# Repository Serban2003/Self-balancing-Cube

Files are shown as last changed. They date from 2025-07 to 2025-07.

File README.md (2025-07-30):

# Self-Balancing Cube (Cubli) with Reaction Wheels and Gyroscope

## Project Overview

This project implements a self-balancing cube (Cubli) using three reaction wheels and a gyroscope-based feedback system. The cube is capable of maintaining balance on its edges or corners using PI control loops executed on an ESP32 microcontroller.

## Objectives

- Design and fabricate a medium-scale Cubli with 3D-printed and off-the-shelf components.
- Implement and tune PI controllers for real-time balance using motor and IMU data.
- Validate closed-loop performance and test real-time response to external disturbances.
- Lay the foundation for further development, such as corner recovery or adaptive control.

## Hardware Components

| Component | Model/Specs |
|---|---|
| Microcontroller | ESP32 DevKitC |
| IMU Sensor | DF-SEN0142 (MPU6050, 6DOF) |
| Motors | Nidec 24H-series BLDC |
| Power Supply | Tattu R-Line 4S 1800mAh LiPo (14.8V) |
| Step-Down Converter | DFRobot DFR1015 (14.8V to 3.3V) |
| Mechanical Structure | Custom-designed PLA parts (Fusion 360) |
| Fasteners | M3/M4 screws, brass inserts, aluminum hubs |

## Software Stack

- **Platform:** PlatformIO (C/C++)
- **Sensor Processing:** MPU6050 (gyroscope + accelerometer)
- **Control Algorithm:** Discrete-time PI controller
- **Testing Interface:** Bluetooth (SerialBT) & MATLAB (for TF estimation)

## Control Design

1. **Motor Identification**  
   - Data collected using encoder feedback and sent over serial to MATLAB.
   - Transfer functions identified using ARX modeling.

2. **Controller Tuning**  
   - PI controllers tuned in MATLAB using `pidtune` for ωₙ ≈ 13.3 rad/s.
   - Discrete controller applied in Arduino firmware using backward difference method.

3. **Testing & Validation**  
   - Real-time control validated via encoder feedback and serial plots.
   - PID implementation maintains speed tracking and ensures system stability.

## IMU Integration & Normalization

- Gyroscope and accelerometer data is normalized using configuration-dependent scale factors defined in `current_config.h`.
- Output is logged in human-readable and CSV format using utility functions (`utils.h` and `normalizer.h`).

## File Structure

| File | Purpose |
|---|---|
| `main.cpp` | Entry point: initializes MPU6050, prints raw/normalized data |
| `motor.cpp/h` | PID control loop, encoder update, PWM output |
| `IMUQuaternion.cpp/h` | Quaternion math and orientation conversion |
| `normalizer.cpp/h` | Sensor value normalization with scale factors |
| `utils.cpp/h` | Serial print utilities (CSV, readable, binary) |
| `current_config.h` | Config for DLPF, SRD, gyro/acc range, scale constants |
| `data_types.h` | `RawValues`, `NormalizedValues`, `Angle`, `IMUQuaternion` |

## Next Steps

- [x] Validate PI controllers with encoders.
- [ ] Integrate real-time orientation feedback from IMU for full stabilization.
- [ ] Transition to aluminum frame for rigidity and weight savings.
- [ ] Implement corner-jump self-balancing and control from arbitrary position.
- [ ] Explore advanced control: Adaptive, LQR, or MPC.

---

## References

- [ETH Zürich Cubli](https://www.youtube.com/watch?v=n_6p-1J551Y)
- [MathWorks PIDTUNE](https://www.mathworks.com/help/control/ref/pidtune.html)
- [TI BLDC Fundamentals](https://www.ti.com/lit/an/slyp173/slyp173.pdf)
- [MPU6050 Datasheet](https://wiki.dfrobot.com/DF-SEN0142)
- [ESP32 Docs](https://www.espressif.com/en/products/socs/esp32/resources)
- [Nidec 24H BLDC Motors](https://www.nidec.com/)

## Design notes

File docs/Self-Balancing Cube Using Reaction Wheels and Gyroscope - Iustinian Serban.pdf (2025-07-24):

Project for Control Engineering II
Student | Șerban Iustinian-Bogdan | Group | 30135 | Grade

# Self-Balancing Cube Using Reaction Wheels and Gyroscope

University Year: 2024-2025

Author: Șerban Iustinian-Bogdan Group: 30135/2

Project for Control Engineering II
Student | Șerban Iustinian-Bogdan | Group | 30135 | Grade

## Contents

## Figures

Figure 1 - Reaction Wheel | 6
Figure 2 - ESP32-DevKitC | 7
Figure 3 - DF-SEN0142 IMU | 8
Figure 4 - Expansion Board for ESP32 | 8
Figure 5 - Nidec 24H Motor | 9
Figure 6 - DF-DFR1015 Buck Converter | 9
Figure 7 - Tattu R-Line Version 3.0 1800mAh 14.8V LiPo Battery | 9
Figure 8 – Plate | 10
Figure 9 - Plate with Slots for Mounting Brackets | 10
Figure 10 - Corner Piece | 11
Figure 11 - Electronics Support | 11
Figure 12 - Motor Mounting Bracket | 11
Figure 13 - Reaction Wheel | 12
Figure 14 - Motor Assembly | 12
Figure 15 - Electronics Support Assembly | 12
Figure 16 - Aluminum Mounting Hub | 13
Figure 18 - M3/M4 Screws | 13
Figure 17 - M3 Brass Inserts | 13
Figure 19 - Cubli's Power Diagram | 14
Figure 20 - Cubli's Data Diagram | 14
Figure 21 - Cubli's Main Assembly View 1 | 15
Figure 22 - Cubli's Main Assembly View 2 | 15
Figure 23 - MotorID1 Data | 17
Figure 24 - MotorID2 Data | 17
Figure 25 - MotorID3 Data | 18
Figure 26 - Simulated vs. Measured RPM for MotorID1 | 20
Figure 27 - Simulated vs. Measured RPM for MotorID2 | 20
Figure 28 - Simulated vs. Measured RPM for MotorID3 | 21
Figure 29 - Step Response of H0 MotorID1 | 23
Figure 30 - Step Response of H0 MotorID2 | 24
Figure 31 - Step Response of H0 MotorID3 | 24
Figure 32 - Arduino Serial Plotter | 29

## Tables

Table 1 - Motor Data Acquisition MATLAB Code | 16
Table 2 - Motor Transfer Function Estimation MATLAB Code | 19
Table 3 - TF and NMSE of Motors | 21
Table 4 - PID Tuning MATLAB Code | 22
Table 5 - Controllers Transfer Function and H0 Settling Time and Overshoot | 23
Table 6 - Controller Implementation in Arduino | 25

Table 7 - Motor RPM Calculation | 26
Table 8 - Testing Arduino Code | 29

## Equations

Equation 1 - PID Formula | 6
Equation 2 - PI Formula | 7
Equation 3 - NMSE Formula | 19
Equation 4 - Closed-Loop System Formula | 22
Equation 5 - Overshoot Formula | 22
Equation 6 - Setting Time Formula for a Second-Order System | 22

## Acronyms

Symbol | Description
ADC | Analog to Digital Converter
ARX | AutoRegressive with eXogenous input
BLE | Bluetooth Low Energy
BLDC | Brushless Direct Current
COTS | Commercial Off-the-Self
DAC | Digital to Analog Converter
DOT | Degrees of Freedom
I2C | Inter-Integrated Circuit
IMU | Inertial Measurement Unit
NMSE | Normalized Mean Square Error
PID | Proportional – Integral – Derivative
PLA | Polylactic Acid
PPR | Pulses per Revolution
PWM | Pulse Width Modulation
RPM | Rotations Per Minute
SPI | Serial Peripheral Interface
TF | Transfer Function
UART | Universal Asynchronous Receiver/Transmitter
ZOH | Zero-Order Hold

## 1. Project Overview

This project presents the design and implementation of a self-balancing cube (Cubli) that uses reaction wheels and a gyroscope to maintain balance on one of its edges or corners. The system is controlled using PID controllers that process sensor data and apply corrective torques via reaction wheels.

The goal is to demonstrate how dynamic actuation and feedback control can stabilize an inherently unstable system, achieving a visually impressive and technically challenging balance.

## 2.Objectives

- Design and assemble a medium-scale Cubli.
- Implement a control system to balance the Cubli on its edge using feedback from sensors.
- Tune and optimize the PID controllers to ensure stability and fast recovery from perturbations.
- Demonstrate the cube’s ability to balance autonomously after disturbances.

## 3. Methodology

The Cubli operates based on the principle of dynamic balancing using reaction wheels. Unlike passive mechanical stabilization, this system actively controls its orientation by accelerating or decelerating internal flywheels, generating the necessary reaction torques to counteract external disturbances.

## 3.1. Reaction Wheels

A reaction wheel is a spinning mass mounted inside the cube. When the motor changes the wheel’s rotational speed, the cube experiences an equal and opposite torque (due to the conservation of angular momentum), allowing it to adjust its body orientation without external supports:

- Accelerating a reaction wheel clockwise applies a counterclockwise torque to the cube.
- Decelerating or braking the wheel applies torque in the opposite direction.

With three orthogonal reaction wheels (aligned along X, Y, and Z axes), the system can generate controlled torques in all rotational directions, enabling balance on an edge or even a corner.

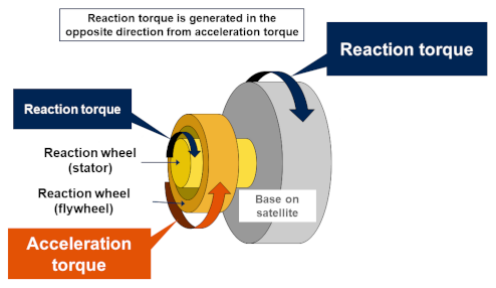
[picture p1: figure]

Figure 1 - Reaction Wheel

## 3.2. PID Controller

A PID controller is a widely used feedback control mechanism that calculates an error value between a desired setpoint and a measured process variable and then applies a corrective action to minimize that error over time.

It works by combining three control terms:

- Proportional (P): Corrects the error in proportion to its current size.
- Integral (I): Corrects accumulated past errors by integrating over time.
- Derivative (D): Predicts future errors by calculating the rate of change.

The controller’s output is computed using the formula:

u(t) = Kp ⋅ e(t) + Ki ⋅ ∫ e(t)dt + Kd ⋅ dtde(t)

Equation 1 - PID Formula

Where:

- u(t) = control output (e.g., motor command)
- e(t) = error signal (desired value – measured value)
- Kp,Ki,Kd = tunable proportional, integral, and derivative gains

In the Cubli project, the controller continuously adjusts the speed of the reaction wheels to apply the right torque and maintain the cube’s balance, even in the presence of disturbances or noise.

3.2.1. Controller Choice

Although a full PID controller includes proportional, integral, and derivative terms, for this project a PI controller was implemented instead.

u(t) = Kp ⋅ e(t) + Ki ⋅ ∫ e(t)dt

Equation 2 - PI Formula

The derivative term (D) was found to be unnecessary because:

- The system dynamics were relatively slow, and proportional plus integral control was sufficient to achieve stable balance.
- The derivative term tended to amplify noise from the sensors (especially the IMU gyroscope), which could introduce instability rather than improve performance.
- Simplifying to a PI controller reduced computational complexity on the ESP32, leaving more resources available for real-time processing.

Thus, the PI controller effectively balances the Cubli by combining:

- Proportional action (P) to respond quickly to current errors, and
- Integral action (I) to eliminate steady-state errors over time.

This approach provided a robust and efficient control solution without the added complexity or sensitivity of the derivative term.

## 4. System Architecture

## 4.1. Electronic Components

The Cubli’s electronic system integrates several carefully selected components that work together to achieve precise sensing, control, and actuation. The following subsections describe the key electronic components used in the Cubli’s assembly and their specific functions within the system.

4.1.1. Microcontroller

The microcontroller used was the ESP32-DevKitC, a compact development board featuring the ESP32-WROOM-32D module, equipped with a dual-core 32-bit Xtensa® microprocessor, Wi-Fi, and Bluetooth (Classic + BLE) connectivity.

Key highlights:

- 38-pin variant for more I/O access | Figure 2 - ESP32-DevKitC

- Rich set of digital and analog peripherals (ADC, DAC, PWM, SPI, I2C, UART)
- Integrated antenna and RF balun
4.1.2. Inertial Measurement Unit (IMU)

The IMU used for this project is the DF-SEN0142, a compact IMU module based on the MPU-6050 chip, offering 6 DOF - combining a 3-axis gyroscope and a 3-axis accelerometer on a single chip.

Figure 3 - DF-SEN0142 IMU
4.1.3. Expansion board for ESP32

The project uses an expansion board, designed to simplify prototyping and development with the ESP32-DevKitC modules. This expansion board provides easy access to all GPIO pins through labeled headers and includes onboard power regulation.

Figure 4 - Expansion Board for ESP32
4.1.4. Motors

The project uses Nidec 24H-series brushless DC motors, known for their high precision, compact design, and reliable performance in applications requiring precise speed and torque control.

Key features:

- 3-Phase, 12-Pole BLDC design
- Logic-controlled clockwise or counterclockwise
- Quiet operation and low inertia
- PWM speed control and brake function

- Dual-channel phase-tracking encoder, a high-resolution encoder output (quadrature signals) allows for detailed phase tracking and fine-grained position/speed measurement.

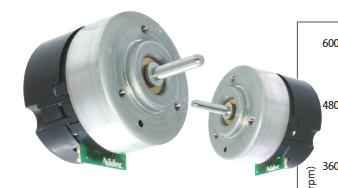
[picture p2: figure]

Figure 5 - Nidec 24H Motor
4.1.5. DC/DC Step-Down Converter

The DF-DFR1015 is a compact step-down (buck) converter module designed to efficiently reduce higher input voltages to stable lower output voltages, making it ideal for supplying power to sensitive electronic components like microcontrollers and sensors. In this project, it is used to step down the 14.8V Li-Po battery voltage to 3.3V, ensuring reliable and safe power delivery to the IMU.

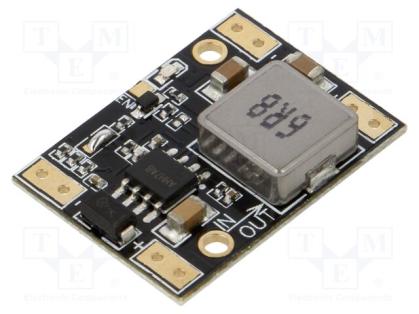
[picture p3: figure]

Figure 6 - DF-DFR1015 Buck Converter
4.1.6. Battery

The Tattu R-Line Version 3.0 LiPo battery is used in this project to provide a high-performance power source for the entire Cubli system. With a 4S1P configuration (four cells in series), it delivers 14.8V nominal voltage and supports extremely high discharge rates (120C continuous).

Figure 7 - Tattu R-Line Version 3.0 1800mAh 14.8V LiPo Battery

## 4.2. Mechanical

The Cubli’s mechanical system was entirely modeled from scratch using Autodesk Fusion
360. All structural components were 3D printed using PLA material, allowing for rapid prototyping and iterative improvement. Each mechanical part has been engineered to interface with the electronic and control systems. The following subsections provide a detailed overview of the key mechanical components used in the Cubli’s assembly.
4.2.1. 3D Printed Parts

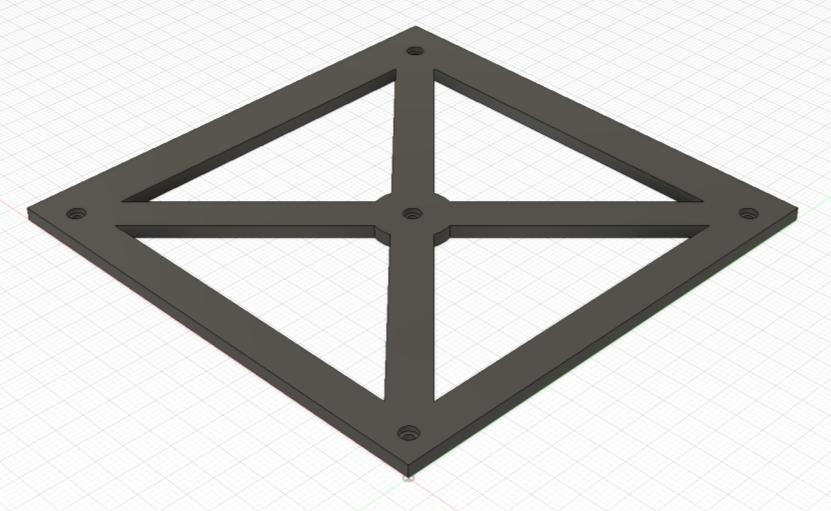
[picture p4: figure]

Figure 8 – Plate

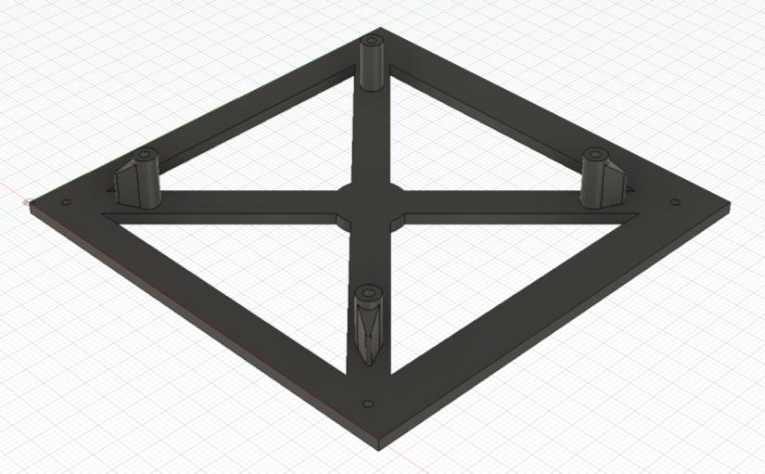
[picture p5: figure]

Figure 9 - Plate with Slots for Mounting Brackets

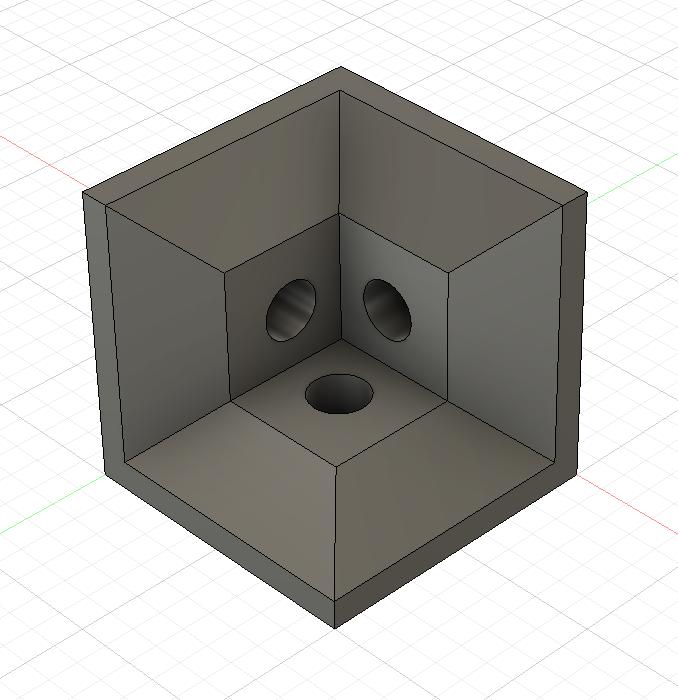
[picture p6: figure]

Figure 10 - Corner Piece

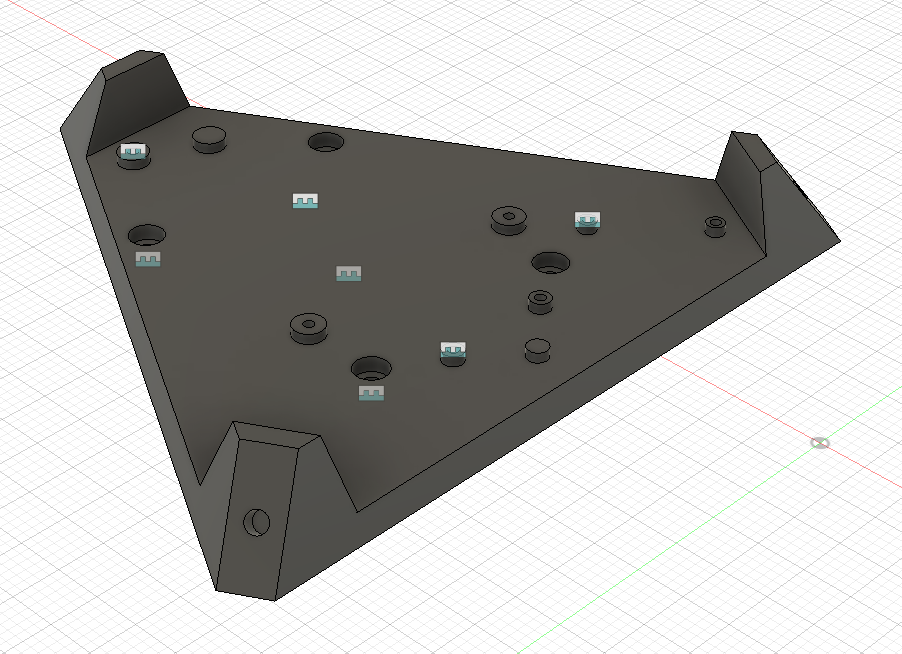
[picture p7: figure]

Figure 11 - Electronics Support

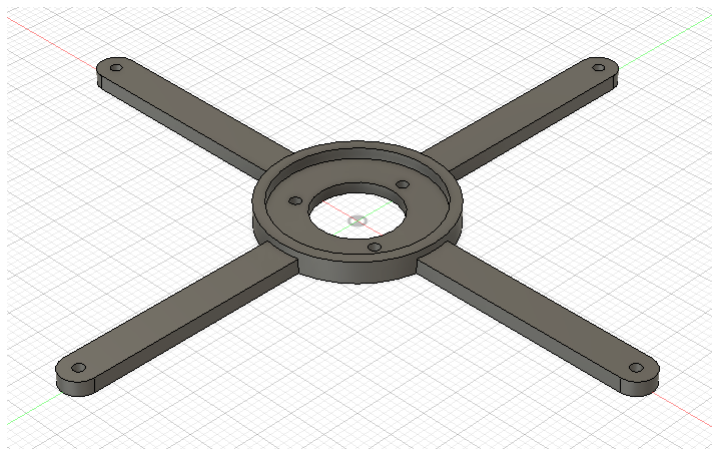
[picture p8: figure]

Figure 12 - Motor Mounting Bracket

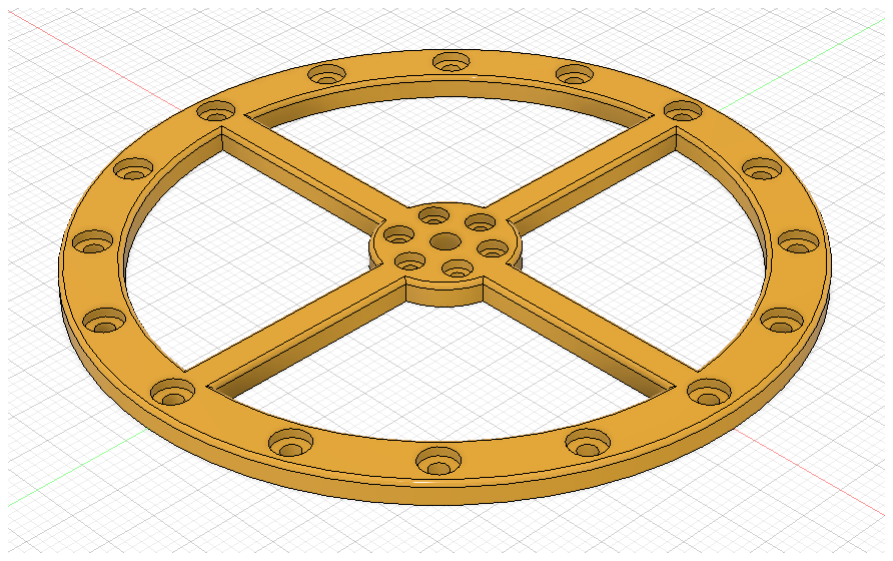
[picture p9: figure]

Figure 13 - Reaction Wheel

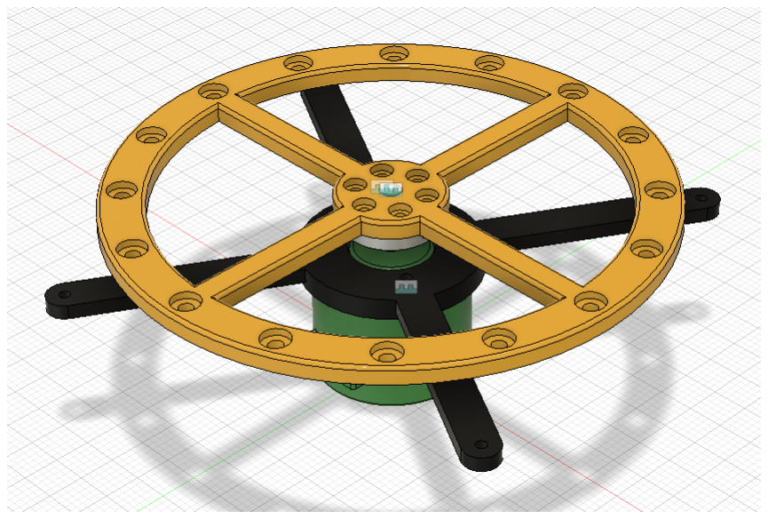
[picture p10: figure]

Figure 14 - Motor Assembly

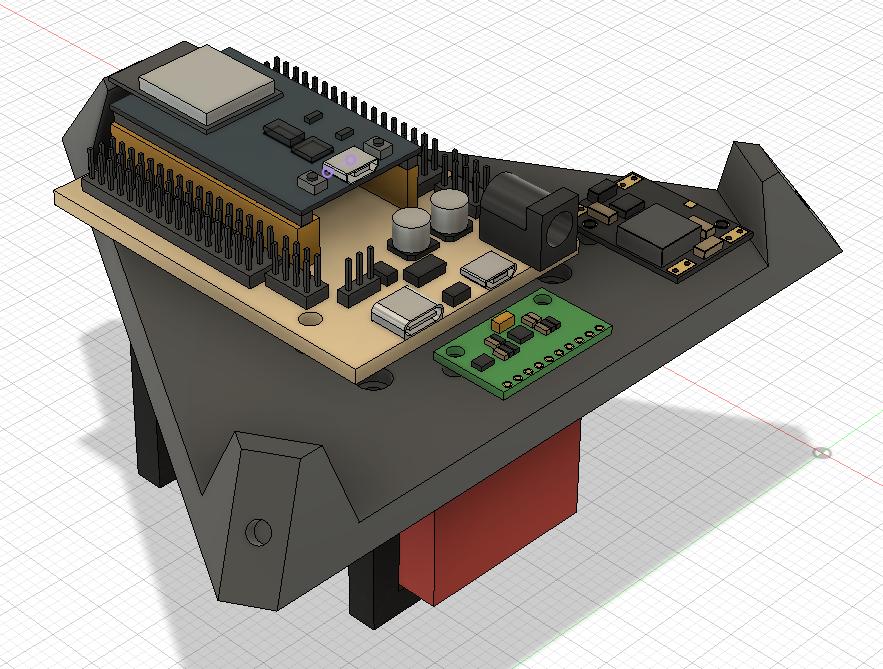
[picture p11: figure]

Figure 15 - Electronics Support Assembly

4.2.2. COTS Parts

In the mechanical assembly of the Cubli, several commercial off-the-shelf components were used to ensure reliable performance and secure integration. Brass inserts (Figure 18) were embedded into the 3D-printed PLA parts to provide durable, wear-resistant threading for repeated assembly and disassembly. M3 and M4 screws and nuts (Figure 17) were employed throughout the build, serving both to fasten structural elements and to add to the weight of the reaction wheels. To interface the motor shafts with the custom-designed reaction wheels, an aluminium mounting hub (Figure 16) was used, ensuring a strong and precise mechanical connection between the motor and the rotating mass. All screws and critical fasteners were secured using Loctite threadlocker to prevent loosening under vibration and dynamic loads, ensuring mechanical stability during operation.

## 4.3. Connection Diagram

The following diagrams (Figure 19 and Figure 20) illustrate the power and signal distribution of the Cubli system. The main power is supplied by a 14.8V 4S1P LiPo battery. A DC-DC Step-Down Module (DFR1015) reduces the voltage to 3.3V, providing stable power to the DF-SEN0142 IMU. The ESP32 DevKitC acts as the central controller, receiving orientation data from the IMU and encoder feedback from the Nidec 24H motors, running the PI control algorithm, and sending control commands to the three motors. Both the motors and the ESP32 draw their primary power directly from the battery’s high-voltage line, while the integrated motor encoders receive regulated 5V power from the ESP32 expansion board. All components share a common ground to ensure a consistent electrical reference and prevent signal disruptions. This tightly integrated system enables real-time sensing, precise control, and rapid actuation, allowing the Cubli to maintain stable dynamic balance.

Figure 16 - Aluminum Mounting Hub | Figure 18 - M3 Brass Inserts | Figure 17 - M3/M4 Screws

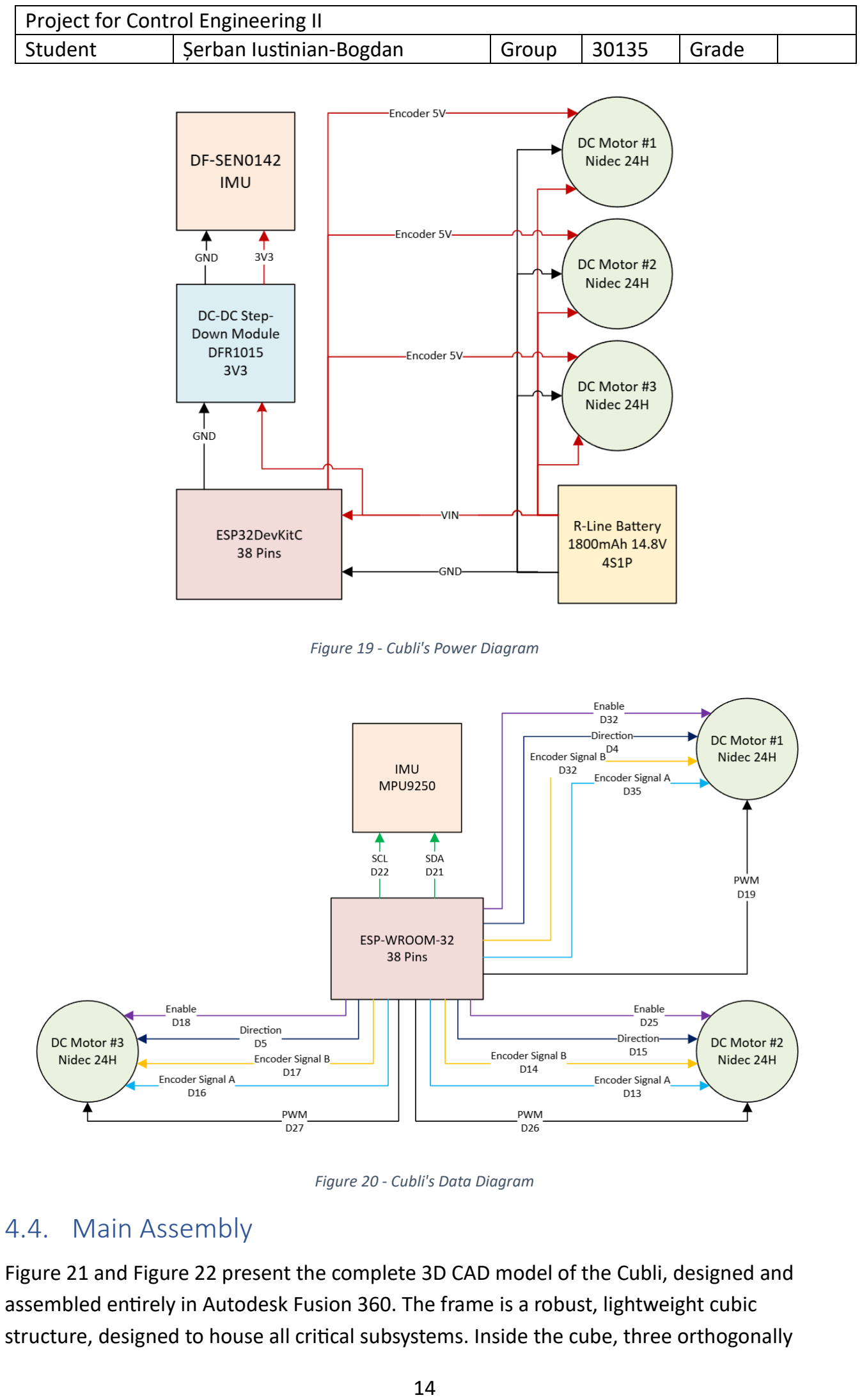
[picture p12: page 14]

Figure 19 - Cubli's Power Diagram

Figure 20 - Cubli's Data Diagram

## 4.4. Main Assembly

Figure 21 and Figure 22 present the complete 3D CAD model of the Cubli, designed and assembled entirely in Autodesk Fusion 360. The frame is a robust, lightweight cubic structure, designed to house all critical subsystems. Inside the cube, three orthogonally mounted reaction wheel assemblies—driven by Nidec 24H motors—enable precise torque generation along the X, Y, and Z axes. The ESP32 controller board and connected electronics are securely mounted on an internal platform, ensuring compact integration and minimal wiring complexity. The design prioritizes both mechanical rigidity and easy access for maintenance and adjustments, providing an optimized layout for balancing operations and control experiments.

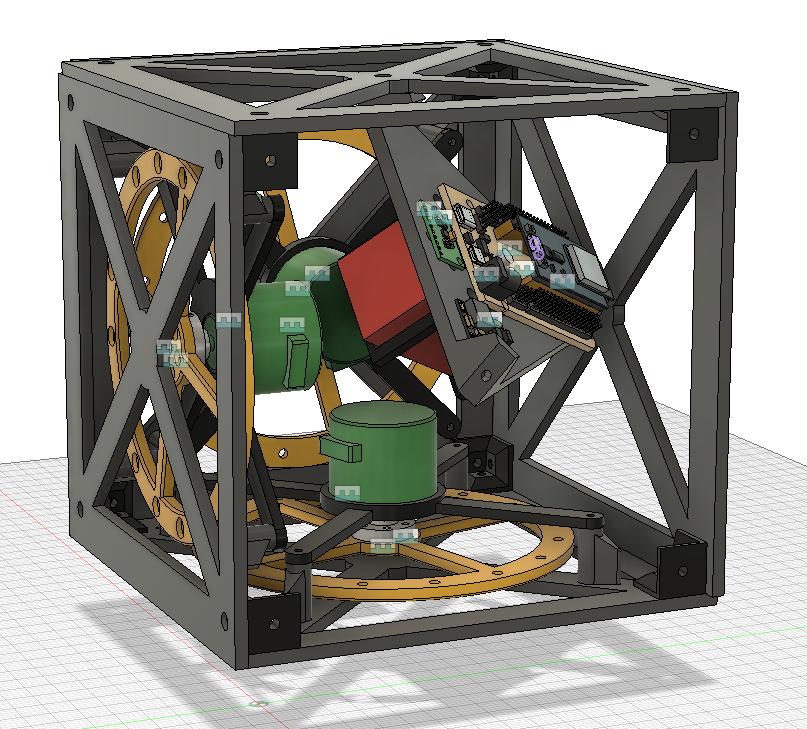
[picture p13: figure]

Figure 21 - Cubli's Main Assembly View 1

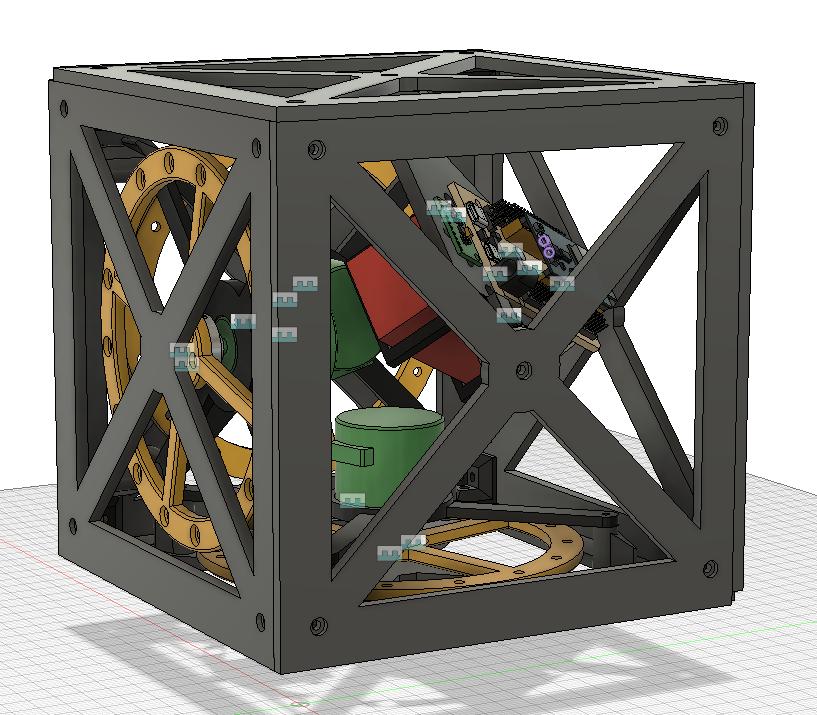
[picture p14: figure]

Figure 22 - Cubli's Main Assembly View 2

## 5. Control System Design

## 5.1. Motor Data Acquisition

In this section, a MATLAB script was implemented to acquire real-time motor performance data over a serial connection. The system connects to the microcontroller through a specified COM port and baud rate. The script creates a ‘serialport’ object to handle incoming data and listens for a set duration of 25 seconds.

Within the main loop, the script continuously checks for available bytes in the serial buffer. When a line is received, it expects a comma-separated string with three values: input command (control signal sent to the motor), elapsed time (in milliseconds), and measured motor speed (in RPM). These values are parsed, converted to appropriate units, and stored in MATLAB arrays.

After the logging duration ends, the serial connection is properly cleared to free system resources. The collected data is then organized into a MATLAB table with three columns— Input, Time_s, and Speed_RPM—and exported as a CSV file, which serves as a structured log of the motor’s response over time and can be further analyzed or visualized in MATLAB or other data processing tools.

comPort = "COM8";
baudRate = 115200;
duration = 25;

s = serialport(comPort, baudRate); flush(s);

input = [];
time = [];
rpm = [];
startTime = datetime('now');

disp("Logging...");

while seconds(datetime('now') - startTime) < duration if s.NumBytesAvailable > 0
line = readline(s);
data = sscanf(line, '%f,%f,%f');
if numel(data) == 3
input(end+1) = data(1);
time(end+1) = data(2) / 1000; % ms to seconds rpm(end+1) = data(3);
end
end
end

clear s
disp("Logging complete.");

T = table(input', time', rpm', 'VariableNames', {'Input', 'Time_s', 'Speed_RPM'}); writetable(T, 'motor_data.csv');
Table 1 - Motor Data Acquisition MATLAB Code

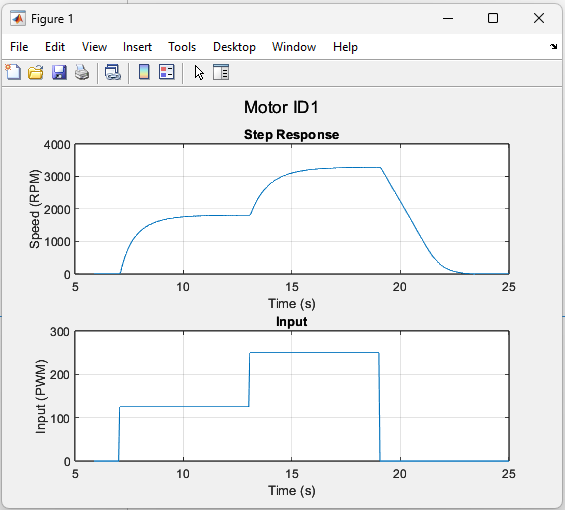
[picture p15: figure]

Figure 23 - MotorID1 Data

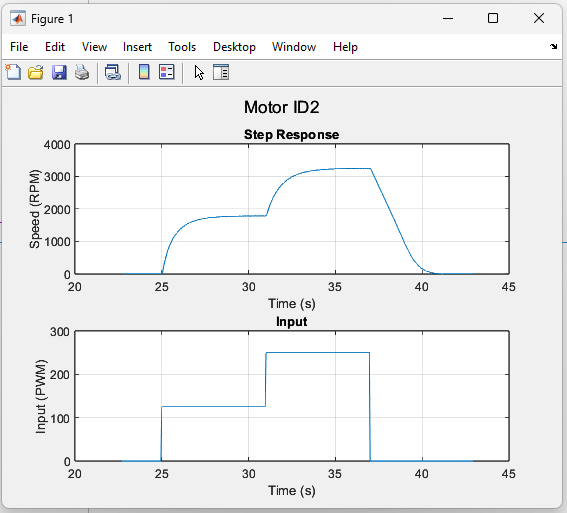
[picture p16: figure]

Figure 24 - MotorID2 Data

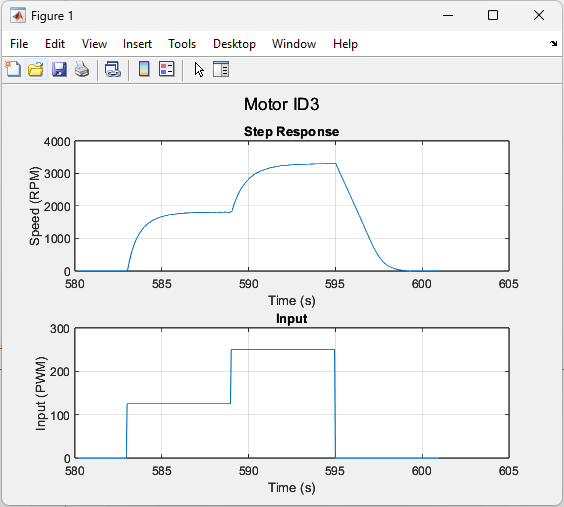
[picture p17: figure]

Figure 25 - MotorID3 Data

## 5.2. Motor Transfer Function Estimation

clc; close all; clear all;

dataTable_motorID1 = readtable("motor_data_ID1.csv"); dataTable_motorID2 = readtable("motor_data_ID2.csv"); dataTable_motorID3 = readtable("motor_data_ID3.csv");

inputArray_motorID1 = dataTable_motorID1.Input(5:260); valueArray_motorID1 = dataTable_motorID1.Speed_RPM(5:260);

inputArray_motorID2 = dataTable_motorID2.Input(27:282); valueArray_motorID2 = dataTable_motorID2.Speed_RPM(27:282);

inputArray_motorID3 = dataTable_motorID3.Input(38:293); valueArray_motorID3 = dataTable_motorID3.Speed_RPM(38:293);

inputArray_motorID1_id = inputArray_motorID1(145:end); valueArray_motorID1_id = valueArray_motorID1(145:end);

inputArray_motorID2_id = inputArray_motorID2(141:end); valueArray_motorID2_id = valueArray_motorID2(141:end);

inputArray_motorID3_id = inputArray_motorID3(141:end);
valueArray_motorID3_id = valueArray_motorID3(141:end);

iddata_motorID1_id = iddata(valueArray_motorID1_id, inputArray_motorID1_id, 0.05); iddata_motorID2_id = iddata(valueArray_motorID2_id, inputArray_motorID2_id, 0.05); iddata_motorID3_id = iddata(valueArray_motorID3_id, inputArray_motorID3_id, 0.05);

TF_motorID1 = calculateTF(inputArray_motorID1_id, valueArray_motorID1_id, 2100, 1); TF_motorID2 = calculateTF(inputArray_motorID2_id, valueArray_motorID2_id, 1782, 2); TF_motorID3 = calculateTF(inputArray_motorID3_id, valueArray_motorID3_id, 1806, 3);

function TF = calculateTF(input_data, output_data, initial_cond, motorID) iddata_motor = iddata(output_data, input_data, 0.05);
arx_model = arx(iddata_motor, [1 1 1]);
[num, den] = tfdata(arx_model, 'v');
[A, B, C, D] = tf2ss(num, den);

y_calc = dlsim(A', C', B', D', input_data, initial_cond); TF = minreal(tf(arx_model));

figure;
plot(1:length(y_calc), [y_calc, output_data]);
grid on;
legend("Y\_calc", "Y\_real");
title("MotorID" + motorID);
xlabel("Sample Time");
ylabel("RPM");
nmse = norm(output_data - y_calc) / norm(output_data - mean(output_data)) * 100; end
Table 2 - Motor Transfer Function Estimation MATLAB Code

In this section, a MATLAB code was created to estimate the transfer functions of the three motors using recorded experimental data. The script begins by reading CSV files that contain the input signals and measured RPM outputs for each motor.

To focus on the most relevant data segments, specific index ranges are selected for each motor, trimming out initial transients or noise. These refined datasets are then converted into MATLAB’s ‘iddata’ format, which is used for system identification tasks.

The core of the analysis is handled by the custom calculateTF function. For each motor, this function:

1. Constructs an ARX model using the input and output data.
2. Converts the resulting discrete transfer function into state-space form.
3. Simulates the system response using ‘dlsim’ and compares the simulated (Y_calc) vs. actual (Y_real) motor speeds.
4. Plots the comparison for visual inspection, showing how well the identified model fits the real system behavior.

Finally, the transfer function is simplified using ‘minreal’ to remove insignificant states, making the model easier to interpret and use in further control system design or simulation.

To quantify how well the simulated model output matches the real measured system output, the Normalized Mean Square Error (NMSE) metric was used. The NMSE compares the squared error between the actual output y and the model’s simulated output ŷ, normalized by the variance of the actual output.

The NMSE is calculated using the formula:

NMSE =

∑ (yi − ŷ i
)
N | 2
i=1
∑ | (yi − yˉ i )
N | 2
i=1

Equation 3 - NMSE Formula

where:

- yi = actual measured output at sample i

- ŷ
i

= simulated model output at sample i

- yˉ = mean value of the measured output y
- N = total number of samples

This chapter provides an essential step in characterizing the dynamic behavior of each motor, which is crucial for tasks like controller design, performance prediction, and closed-loop system optimization.

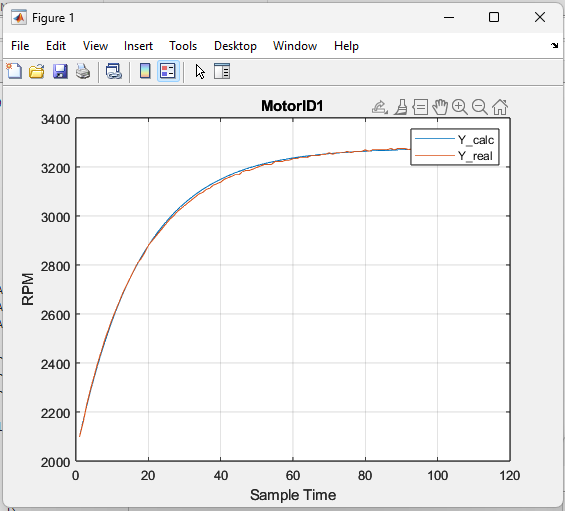
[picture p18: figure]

Figure 26 - Simulated vs. Measured RPM for MotorID1

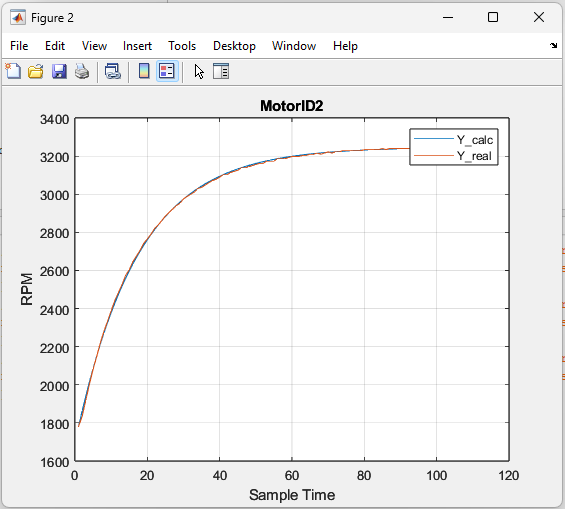
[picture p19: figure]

Figure 27 - Simulated vs. Measured RPM for MotorID2

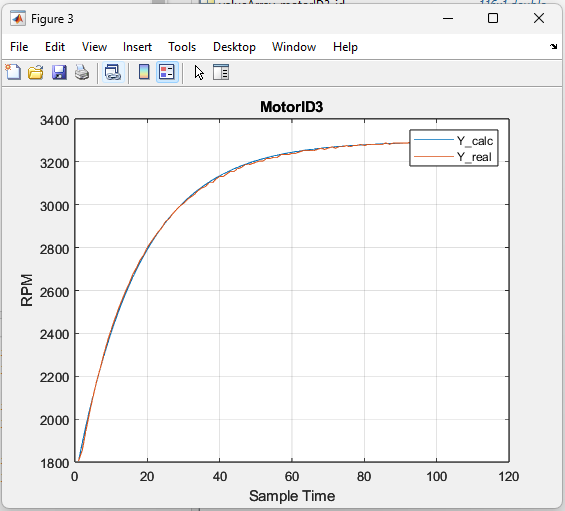
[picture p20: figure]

Figure 28 - Simulated vs. Measured RPM for MotorID3

The transfer functions Hf(s) for all three motors show very similar system dynamics, with nearly identical coefficients, indicating consistent motor behavior across units. The discrete transfer functions Hf(z

−1
) were calculated using the zero-order hold (ZOH) method with a sampling time Te= 0.05. The NMSE values (2.30%, 1.84%, 2.05%) reflect low normalized errors, confirming that the identified models accurately capture each motor’s response with good fit quality.
MotorID | ID1 | ID2 | ID3
TF Hf(s) | 14.96 s + 1.141 | 15.08 s + 1.161 | 15.03 s + 1.141
Discrete TF −1 Hf(z ) | −1 0.7271 ∙ z −1 1 − 0.9445 ∙ z | −1 0.7325 ∙ z −1 1 − 0.9436 ∙ z | −1 0.7304 ∙ z −1 1 − 0.9446 ∙ z
NMSE | 2.3033 | 1.8369 | 2.0452
Table 3 - TF and NMSE of Motors

## 5.3. PI Tuning

Using MATLAB’s ‘pidtune’ function, a PI controller is automatically tuned for the discretized TF of each motor to achieve a desired closed-loop bandwidth (or the natural frequency ωn) of 13.55 rad/s. The resulting continuous controller is then converted into discrete form, yielding Hc(z

−1
), which is simplified using ‘minreal’ to remove unnecessary dynamics.

Finally, the script simulates the closed-loop step response of the combined system Hc(z

−1
) × Hf(z

−1
) with unity feedback over 1 second, providing a visual evaluation of the controller’s performance.

The formula for the closed-loop system Ho is:

Ho =

Hc × Hf
1 + Hc × Hf

Equation 4 - Closed-Loop System Formula

Hf_discret = c2d(Hf, 0.05, 'zoh');
Hf_discret.Variable = "z^-1";

% Use pidtune to get PI controller
[c_tuned, info] = pidtune(Hf_discret, 'PI', 13.33) % 13.33 rad/s desired bandwidth % Discretize controller
Hc_discret = minreal(tf(c_tuned));
Hc_discret.Variable = 'z^-1'
figure;
step(feedback(series(Hf_discret, Hc_discret), 1), 1);
title("Step Response for Motor ID1");
Table 4 - PID Tuning MATLAB Code

For this project, the following performances for the closed-loop system were imposed:

- Settling time of Ts ≤ 0.5s
- Overshoot σ ≤ 10%

The required damping ratio corresponding to the specified overshoot is calculated using the below formula, which implies a damping ration of ζ ≈ 0.6.

σ = e

−πζ
√1−ζ
2

Equation 5 - Overshoot Formula

For a second-order system, the settling time can be approximated using the formula:

Ts ≈

4
ζωn

Equation 6 - Setting Time Formula for a Second-Order System

Given the imposed performances, the resulting natural frequency can be calculated as:

ωn =

4
ζTs

≥

4
0.6 × 0.5

= 13.33 rad/s

Thus, the target natural frequency for the system is approximately 13.33 rad/s.

The resulting controllers for each motor can be visualized in the following table:

MotorID | ID1 | ID2 | ID3
Discrete Controller Hc(z −1 ) | −1 0.9272 − 0.7636 ∙ z −1 1 − z | −1 0.9201 − 0.7569 ∙ z −1 1 − z | −1 0.9229 − 0.7601 ∙ z −1 1 − z

Ho Settling Time Ts [s] | 0.651 | 0.648 | 0.651
Ho Overshoot σ [%] | 13.1 | 13.1 | 13.1

Table 5 - Controllers Transfer Function and H0 Settling Time and Overshoot

Although the continuous-time design may meet the imposed settling time and overshoot specifications, the performances in the discrete implementations show deviations — notably, slightly longer settling times and higher overshoot. This discrepancy is often caused by the process of converting continuous-time controllers to discrete form, which introduces approximation errors that subtly change the system's dynamic behavior.

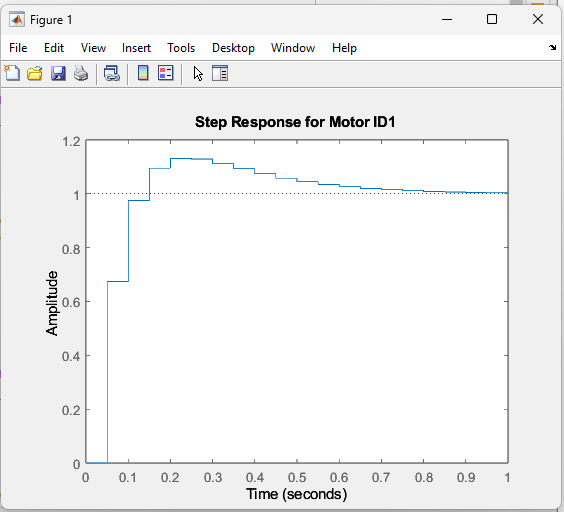
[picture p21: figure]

Figure 29 - Step Response of H0 MotorID1

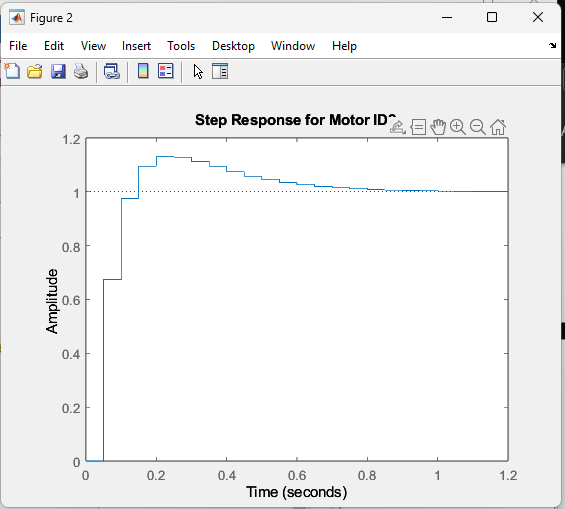
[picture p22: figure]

Figure 30 - Step Response of H0 MotorID2

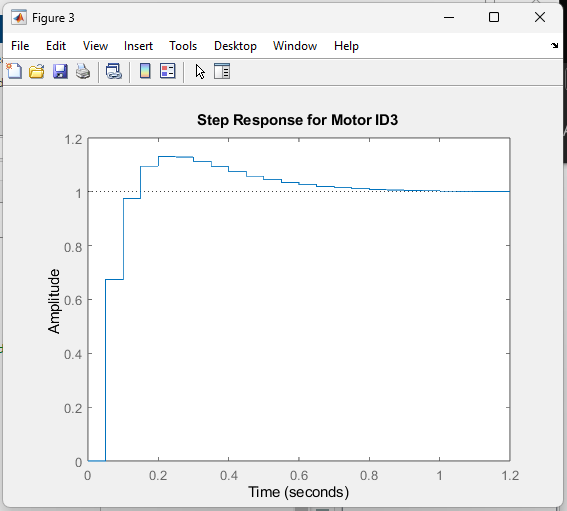
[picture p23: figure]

Figure 31 - Step Response of H0 MotorID3

## 5.4. Arduino Controller Implementation

volatile double M1_command[2];
volatile double M1_error[2];
const double M1_PID_coef[3] = {1, 0.9272, -0.7636};

void M1_PID(int target_rpm, int current_rpm){

M1_error[1] = M1_error[0];
M1_error[0] = abs(target_rpm) - abs(current_rpm);

M1_command[1] = M1_command[0];
M1_command[0] = M1_PID_coef[0] * M1_command[1] + M1_PID_coef[1] * M1_error[0] + M1_PID_coef[2] * M1_error[1];

Serial.print("Command: ");
Serial.println(M1_command[0]);

if(M1_command[0] > 255) M1_command[0] = 255;
else if(M1_command[0] < -255) M1_command[0] = -255;

if(target_rpm < 0)
M1_Control(-M1_command[0]);
else
M1_Control(M1_command[0]); }

void M1_Control(int sp) {
if (sp > 0) digitalWrite(M1_DIR, LOW); else digitalWrite(M1_DIR, HIGH); ledcWrite(M1_PWM, abs(sp));
}
Table 6 - Controller Implementation in Arduino

This Arduino code implements a discrete PI controller for motor M1, where it calculates the control command based on the difference between the target RPM and the measured current RPM. It updates the current and previous error values, applies a recursive control equation using predefined PID coefficients, and ensures the resulting command stays within the allowed PWM range of −255 to 255. Depending on the sign of the target RPM, it adjusts the control signal’s direction and magnitude, calling the ‘M1_Control’ function to set the motor’s direction pin (M1_DIR) and apply the PWM output (M1_PWM). Overall, this setup is implemented for each motor.

The current motor’s RPM is calculated based on the motor encoder counts. The encoder generates PPR (pulses per revolution), and the system samples the counts every 50 milliseconds. The time step ‘dt’ is calculated in seconds. The formula for ‘M1_rpm’ converts the count rate into RPM, where the factor of 2 accounts for quadrature encoding (since each encoder pulse gives two counts).

The ‘M1_UpdateEncoder()’ function updates ‘M1_enc_count’ by reading encoder signals ‘M1_ENC_SIG_A’ and ‘M1_ENC_SIG_B’; if both signals match, it increments the count, and if they differ, it decrements the count, effectively tracking both position and direction of the motor shaft.

int PPR = 100; // Pulses per revolution
unsigned long sampleInterval = 50; // ms
float dt = sampleInterval / 1000.0;
float M1_rpm = (M1_enc_count / dt) * (60.0 / (PPR * 2));

void M1_UpdateEncoder() {
int A = digitalRead(M1_ENC_SIG_A);
int B = digitalRead(M1_ENC_SIG_B);

if (A == B) {
M1_enc_count++;
} else {
M1_enc_count--;
}
}
Table 7 - Motor RPM Calculation

## 6. Testing

The provided code is designed as part of the testing setup to validate the performance of the PI controller for the three independent motors. During testing, Bluetooth commands are received via ‘SerialBT’, allowing real-time control instructions to be sent to each motor. The command format <motor_number> <value> is used to set a target RPM or to issue start/stop commands for each motor individually.

At defined intervals, the code reads the encoder pulse counts for each motor, computes their actual RPM, and applies the PI control algorithm if a target RPM is active. This closed-loop feedback ensures that the motors dynamically adjust their speed to match the desired setpoint.

To facilitate testing and tuning, the system outputs the measured RPMs and current control signal values over the serial interface. This feedback enables observation of how the PI controller responds to setpoint changes, external disturbances, or start/stop commands, ensuring stable and accurate motor speed control prior to integration into the full Cubli system.

void loop() {
if (SerialBT.available()) {
String incoming = SerialBT.readStringUntil('\n'); // Read until newline incoming.trim(); // Remove any extra \r or spaces

Serial.print("Received: ");
Serial.println(incoming);

int spaceIndex = incoming.indexOf(' '); if (spaceIndex != -1) {

String firstPart = incoming.substring(0, spaceIndex); String secondPart = incoming.substring(spaceIndex + 1);

int motor = firstPart.toInt();
String valueStr = secondPart;

// Check if the second part is a number
bool isNumber = true;
for (size_t i = 0; i < valueStr.length(); i++) { char c = valueStr.charAt(i);
if (!isDigit(c) && !(i == 0 && c == '-')) { isNumber = false;
break;
}
}

switch(motor){
case 1:{
if(isNumber){
int RPM = valueStr.toInt(); M1_target_RPM = RPM;
}
else if(valueStr == "stop"){ M1_target_RPM = 0;
M1_Control(0);
digitalWrite(M1_EN, HIGH); }
else if(valueStr == "start"){ digitalWrite(M1_EN, LOW);
}
break;
}
case 2:{
if(isNumber){
int RPM = valueStr.toInt(); M2_target_RPM = RPM;
}
else if(valueStr == "stop"){ M2_target_RPM = 0;
M2_Control(0);
digitalWrite(M2_EN, HIGH); }
else if(valueStr == "start"){ digitalWrite(M2_EN, LOW);
}
break;
}

case 3:{
if(isNumber){
int RPM = valueStr.toInt(); M3_target_RPM = RPM;
}
else if(valueStr == "stop"){ M3_target_RPM = 0;
M3_Control(0);
digitalWrite(M3_EN, HIGH); }
else if(valueStr == "start"){ digitalWrite(M3_EN, LOW);
}
break;
}
}
} else {
Serial.println("Invalid format, expected: <command> <value>"); }
}
unsigned long currentTime = millis();

if (currentTime - lastTime >= sampleInterval) { noInterrupts();
long M1_count = M1_enc_count;
long M2_count = M2_enc_count;
long M3_count = M3_enc_count;

M1_enc_count = 0;
M2_enc_count = 0;
M3_enc_count = 0;
interrupts();

float dt = sampleInterval / 1000.0;
float M1_rpm = (M1_count / dt) * (60.0 / (PPR * 2)); float M2_rpm = (M2_count / dt) * (60.0 / (PPR * 2)); float M3_rpm = (M3_count / dt) * (60.0 / (PPR * 2));

Serial.print("M1_rpm:");
Serial.print(M1_rpm);
Serial.print(", ");
Serial.print("M2_rpm:");
Serial.print(M2_rpm);
Serial.print(", ");
Serial.print("M3_rpm:");
Serial.print(M3_rpm);
Serial.print(", ");

Serial.print("M1_com:");
Serial.print(M1_com);
Serial.print(", ");
Serial.print("M2_com:");
Serial.print(M2_com);
Serial.print(", ");
Serial.print("M3_com:");
Serial.println(M3_com);

if(M1_target_RPM != 0) M1_PID(M1_target_RPM, M1_rpm); if(M2_target_RPM != 0) M2_PID(M2_target_RPM, M2_rpm); if(M3_target_RPM != 0) M3_PID(M3_target_RPM, M3_rpm); lastTime = currentTime;
}
}

Table 8 - Testing Arduino Code

As a result of the testing process, the motors were confirmed to be functioning perfectly, maintaining stable and accurate speed control across all test conditions, and meeting the required performance for integration into the full Cubli system.

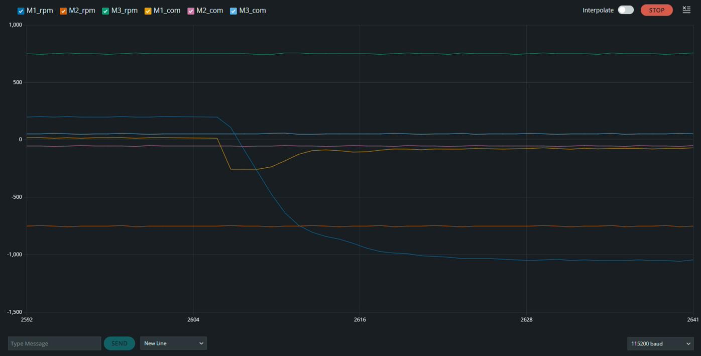
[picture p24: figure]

Figure 32 - Arduino Serial Plotter

## 7.Next Steps

The next steps will focus on testing and integrating the IMU into the control system to enable full closed-loop balancing control. While the current setup has validated the performance of the PI controller and motor actuation, the integration of real-time orientation data from the IMU is essential for allowing the Cubli to sense its tilt and apply corrective actions dynamically. This phase will involve calibrating the IMU, validating sensor readings, and incorporating its data into the control loop to enable the Cubli to balance stably on an edge or corner.

For future improvements, the project aims to make the Cubli more compact and fabricate its structure from aluminium to improve mechanical strength and reduce weight. Additionally, a more robust control strategy will be explored, potentially moving beyond the current PI controller to advanced methods such as adaptive control or model predictive control, providing better disturbance rejection and faster response under complex dynamic conditions. Another improvement is to develop the capability for the Cubli to self-position onto its corner from a flat face, adding an advanced level of autonomy and showcasing its ability to perform dynamic maneuvers beyond static balancing.

## 8. Conclusions

This project successfully demonstrated the development of a functional Cubli prototype, capable of precision motor control using a PI feedback system. Through the integration of brushless DC motors, encoders, a microcontroller, and Bluetooth communication, the system achieved stable and accurate speed regulation, providing a solid base for future balance control. The mechanical structure, fully designed from scratch and made using 3D-printed PLA components, provided a lightweight and modular platform for testing and iteration.

While significant progress was made, particularly in validating the motor control subsystem, the integration of the IMU remains a critical next step to enable full dynamic balancing. Looking ahead, the planned improvements should make the Cubli more powerful, robust, and independent.

## Bibliography

- ETH Zürich, Cubli: A Cube That Can Jump Up, Balance, and Walk Across Your Desk. [Online Video]. Available: https://www.youtube.com/watch?v=n_6p-1J551Y
- Åström, K. J., & Hägglund, T., PID Controllers: Theory, Design, and Tuning. Instrument Society of America, 1995.
- MathWorks, pidtune (PID Tuning) - MATLAB Documentation. [Online]. Available: https://www.mathworks.com/help/control/ref/pidtune.html
- Texas Instruments, Brushless DC Motor Fundamentals. [White Paper]. Available: https://www.ti.com/lit/an/slyp173/slyp173.pdf
- DFRobot, DF-SEN0142 MPU6050 6DOF IMU Datasheet. [Online]. Available: https://wiki.dfrobot.com
- DFRobot, DFR1015 Buck Converter Module. [Product Page]. Available: https://wiki.dfrobot.com/DFR1015
- Espressif Systems, ESP32 Technical Reference Manual. [Online PDF]. Available: https://www.espressif.com/en/products/socs/esp32/resources
- Nidec Corporation, Nidec 24H Series Brushless DC Motor Specifications. [Datasheet]. Available: https://www.nidec.com

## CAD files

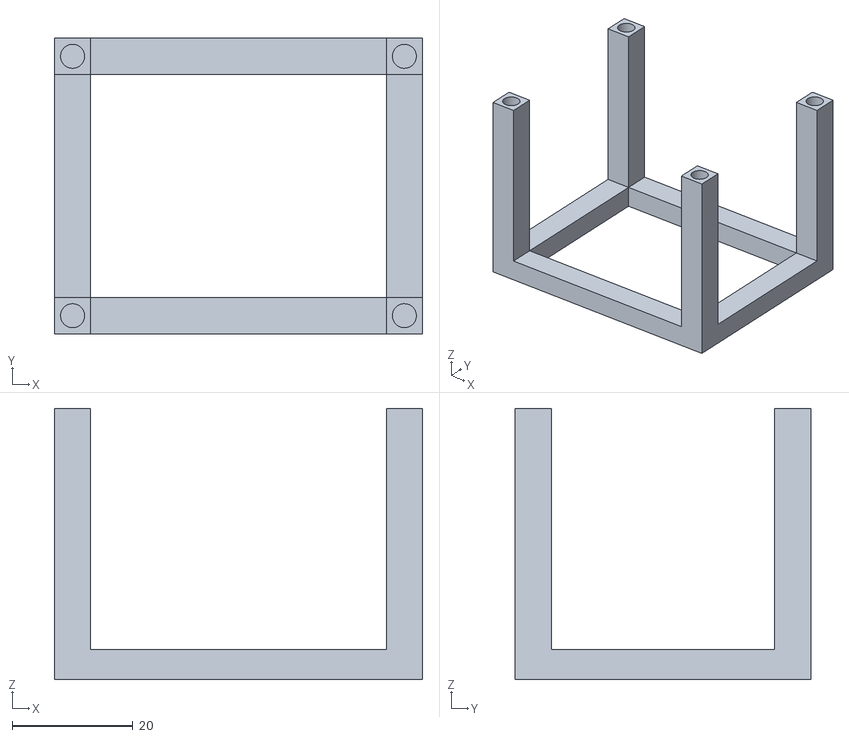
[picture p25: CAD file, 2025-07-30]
docs/3D Model/Battery bracket.stl
61.0 x 49.0 x 45.0

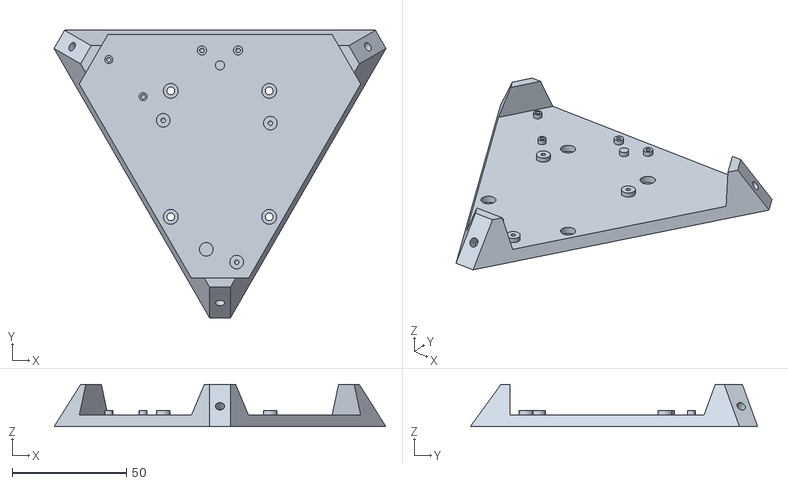
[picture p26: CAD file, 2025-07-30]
docs/3D Model/Support.stl
145.0 x 125.6 x 18.5

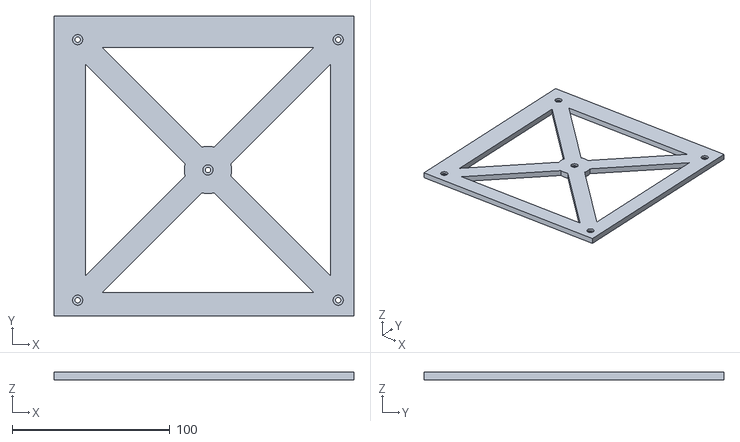
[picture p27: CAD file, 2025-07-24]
docs/3D Model/Plate.stl
190.0 x 190.0 x 5.00

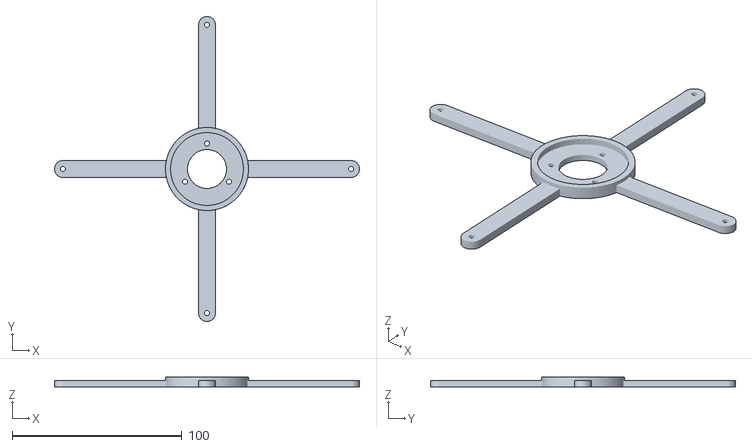
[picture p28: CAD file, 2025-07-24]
docs/3D Model/Motor mounting bracket v13.stl
179.9 x 179.9 x 6.00

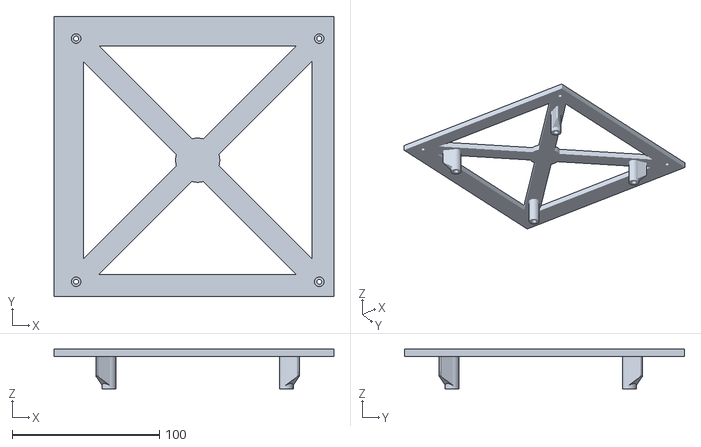
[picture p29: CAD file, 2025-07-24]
docs/3D Model/Plate with mounting brackets v34.stl
190.0 x 190.0 x 27.0

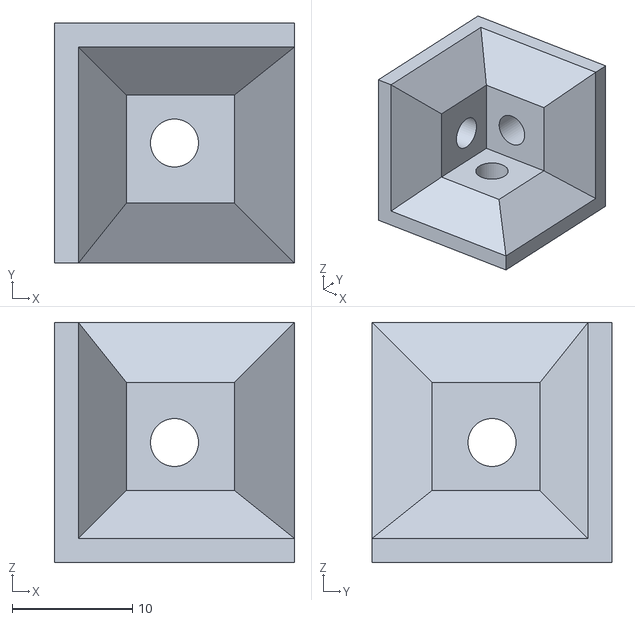
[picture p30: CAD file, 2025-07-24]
docs/3D Model/Corner piece v25.stl
20.0 x 20.0 x 20.0

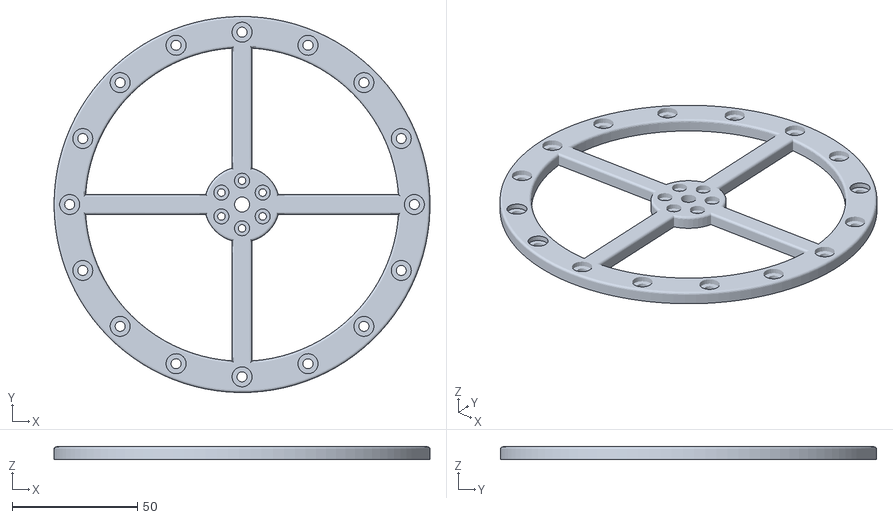
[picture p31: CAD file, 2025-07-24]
docs/3D Model/Reaction Wheel v5.stl
150.0 x 150.0 x 5.00

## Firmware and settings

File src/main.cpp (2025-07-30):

#include <Arduino.h>
#include <esp32-hal-ledc.h>
#include <I2Cdev.h>
#include <MPU6050.h>
#include <Wire.h>
#include <BluetoothSerial.h>
#include "data_types.h"
#include "current_config.h"
#include "normalizer.h"
#include "angle.h"
#include "IMUQuaternion.h"
#include "motor.h"
#include "utils.h"

BluetoothSerial SerialBT;
MPU6050 accelgyro;
I2Cdev i2c;
RawValue accelerometer_raw, gyroscope_raw;
Angle accelerometer_norm, gyroscope_norm;
Angle accelerometer_angle, gyroscope_angle;
Angle currentPosition;

uint32_t sampleTimeMicros = 0;
uint32_t lastSampleTime = 0;
uint32_t lastPrintTime = 0;

void setup() {
    delay(1000);
    SerialBT.begin("Cubli ESP32");
    /* ---------- Motor ID1 ---------- */
    pinMode(M1_EN, OUTPUT);
    digitalWrite(M1_EN, LOW);

    pinMode(M1_DIR, OUTPUT);
    pinMode(M1_ENC_SIG_A, INPUT);
    pinMode(M1_ENC_SIG_B, INPUT);
    attachInterrupt(digitalPinToInterrupt(M1_ENC_SIG_A), M1_updateEncoder, CHANGE);

    pinMode(M1_PWM, OUTPUT);
    ledcAttach(M1_PWM, BASE_FREQ, TIMER_BIT);
    controlMotor(M1_ID, 0);
    brakeMotor(M1_ID, false);
    /* ---------- Motor ID1 ---------- */

    /* ---------- Motor ID2 ---------- */
    pinMode(M2_EN, OUTPUT);
    digitalWrite(M2_EN, LOW);

    pinMode(M2_DIR, OUTPUT);
    pinMode(M2_ENC_SIG_A, INPUT);
    pinMode(M2_ENC_SIG_B, INPUT);
    attachInterrupt(digitalPinToInterrupt(M2_ENC_SIG_A), M2_updateEncoder, CHANGE);

    pinMode(M2_PWM, OUTPUT);
    ledcAttach(M2_PWM, BASE_FREQ, TIMER_BIT);
    controlMotor(M2_ID, 0);
    brakeMotor(M2_ID, false);
    /* ---------- Motor ID2 ---------- */

    /* ---------- Motor ID3 ---------- */
    pinMode(M3_EN, OUTPUT);
    digitalWrite(M3_EN, LOW);

    pinMode(M3_DIR, OUTPUT);
    pinMode(M3_ENC_SIG_A, INPUT);
    pinMode(M3_ENC_SIG_B, INPUT);
    attachInterrupt(digitalPinToInterrupt(M3_ENC_SIG_A), M3_updateEncoder, CHANGE);

    pinMode(M3_PWM, OUTPUT);
    ledcAttach(M3_PWM, BASE_FREQ, TIMER_BIT);
    controlMotor(M3_ID, 0);
    brakeMotor(M3_ID, false);
    
    Wire.begin();
    Serial.begin(115200);

    Serial.println("Testing device connections...");
    Serial.println(accelgyro.testConnection() ? "MPU6050 connection successful" : "MPU6050 connection failed");

    // Data Output Rate = 1000 / (1 + SRD)
    // Output rate must be at least 2x DLPF rate
    I2Cdev::writeByte(MPU6050_IMU_ADDRESS, SRD_CONFIG_ADDRESS, SRD_CONFIG_VALUE); // Set the SRD to 1
    I2Cdev::writeByte(MPU6050_IMU_ADDRESS, DLPF_CONFIG_ADDRESS, DLPF_CONFIG_VALUE); // Set the DLPF to 184HZ by default
    I2Cdev::writeByte(MPU6050_IMU_ADDRESS, GYRO_CONFIG_ADDRESS, GYRO_CONFIG_VALUE); // Configure gyroscope range
    I2Cdev::writeByte(MPU6050_IMU_ADDRESS, ACC_CONFIG_ADDRESS, ACC_CONFIG_VALUE); // Configure accelerometer range
    accelgyro.setSleepEnabled(false);
    delay(1000);
}

void loop() {

    if (SerialBT.available()) {
        String incoming = SerialBT.readStringUntil('\n');
        incoming.trim();
        processCommand(incoming);
    }

    uint32_t elapsedTimeMicros = 0;
    if(sampleTimeMicros > 0) elapsedTimeMicros = micros() - sampleTimeMicros;
    sampleTimeMicros = micros();

    // read raw accel/gyro measurements from device
    accelgyro.getMotion6(&accelerometer_raw.x, &accelerometer_raw.y, &accelerometer_raw.z, &gyroscope_raw.x, &gyroscope_raw.y, &gyroscope_raw.z);
    accelerometer_norm = normalizeAccelerometer(accelerometer_raw);
    gyroscope_norm = normalizeGyroscope(gyroscope_raw);

    accelerometer_angle = computeAccelerometerAngles(accelerometer_norm);
    gyroscope_angle = computeGyroscopeAngles(gyroscope_norm, elapsedTimeMicros);

    // Complementary filter
    currentPosition = computePosition(currentPosition, gyroscope_angle, accelerometer_angle);
    IMUQuaternion rotation = eulerToQuaternion(currentPosition);
   
    sampleTimeMicros = micros();
    if (sampleTimeMicros - lastSampleTime >= SAMPLE_TIME_MS * 1000UL){
        noInterrupts();
        int32_t M1_count = M1_encoderCount;
        int32_t M2_count = M2_encoderCount;
        int32_t M3_count = M3_encoderCount;
        
        M1_encoderCount = 0;
        M2_encoderCount = 0;
        M3_encoderCount = 0;
        interrupts();
        
        float dt = SAMPLE_TIME_MS / 1000.0f;
        float M1_rpm = (M1_count / dt) * (60.0 / (MOTOR_PPR * 2));
        float M2_rpm = (M2_count / dt) * (60.0 / (MOTOR_PPR * 2));
        float M3_rpm = (M3_count / dt) * (60.0 / (MOTOR_PPR * 2));

        #ifdef DEBUG_MOTORS_ENABLED
            Serial.printf("----- RPMs  -----\n");
            Serial.printf("Motor ID 1 > Encoder count: %d, current RPM: %.4f, target RPM: %.4f\n", M1_count, M1_rpm, M1_targetRPM);
            Serial.printf("Motor ID 2 > Encoder count: %d, current RPM: %.4f, target RPM: %.4f\n", M2_count, M2_rpm, M2_targetRPM); 
            Serial.printf("Motor ID 3 > Encoder count: %d, current RPM: %.4f, target RPM: %.4f\n", M3_count, M3_rpm, M3_targetRPM);       
        #endif

        if(M1_targetRPM != 0) M1_PID(M1_targetRPM, M1_rpm);
        if(M2_targetRPM != 0) M2_PID(M2_targetRPM, M2_rpm);
        if(M3_targetRPM != 0) M3_PID(M3_targetRPM, M3_rpm);
        lastSampleTime = sampleTimeMicros;
    }


    if (sampleTimeMicros - lastPrintTime > PRINT_INTERVAL_MS * 1000UL){
        lastPrintTime = sampleTimeMicros;

        //printAngle(currentPosition);
        //printQuaternion(rotation);
        #ifdef DEBUG_ENABLED
            printReadable("Accelerometer Raw", accelerometer_raw);
            printReadable("Accelerometer Norm", accelerometer_norm);
            printReadable("Accelerometer Angle", accelerometer_angle);
            printReadable("Gyroscope Raw", gyroscope_raw);
            printReadable("Gyroscope Norm", gyroscope_norm);
            printReadable("Gyroscope Angle", gyroscope_angle);
            printAngle(currentPosition);
        #endif
    }
}

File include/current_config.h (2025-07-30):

#ifndef CURRENT_CONFIG_H
#define CURRENT_CONFIG_H

/* ---------- MPU6050 ---------- */
#include <MPU6050.h>

#define SRD_CONFIG_VALUE 0x01
#define DLPF_CONFIG_VALUE MPU6050_DLPF_BW_188
#define GYRO_CONFIG_VALUE MPU6050_GYRO_FS_1000
#define ACC_CONFIG_VALUE MPU6050_ACCEL_FS_2
/* ---------- MPU6050 ---------- */

/* ---------- COMPLEMENTARY FILTER ---------- */
#define ALPHA 0.98F
/* ---------- COMPLEMENTARY FILTER ---------- */

/* ---------- DEBUG ---------- */
#define PRINT_INTERVAL_MS 1000
#define SAMPLE_TIME_MS 50
//#define DEBUG_ENABLED 
//#define DEBUG_MOTORS_ENABLED
/* ---------- DEBUG ---------- */

/* ---------- PWM SETUP ---------- */
#define TIMER_BIT  8
#define BASE_FREQ  20000
/* ---------- PWM SETUP ---------- */

/* ---------- MOTOR ID1 ---------- */
#define MOTOR_PPR 100
#define M1_ID 1
#define M1_PWM 19
#define M1_EN 32 // BRAKE
#define M1_DIR 4
#define M1_ENC_SIG_A 35
#define M1_ENC_SIG_B 33
const float M1_PID_COEF[3] = {1.0f, 0.9272f, -0.7636f};
/* ---------- MOTOR ID1 ---------- */

/* ---------- MOTOR ID2 ---------- */
#define M2_ID 2
#define M2_PWM 26
#define M2_EN 25
#define M2_DIR 15
#define M2_ENC_SIG_A 13
#define M2_ENC_SIG_B 14
const float M2_PID_COEF[3] = {1.0f, 0.9201f, -0.7569f};
/* ---------- MOTOR ID2 ---------- */

/* ---------- MOTOR ID3 ---------- */
#define M3_ID 3
#define M3_PWM 27
#define M3_EN 18
#define M3_DIR 5
#define M3_ENC_SIG_A 16
#define M3_ENC_SIG_B 17
const float M3_PID_COEF[3] = {1.0f, 0.9229f, -0.7601f};
/* ---------- MOTOR ID3 ---------- */

/* DO NOT MODIFY ANY BELOW CODE */
#if GYRO_CONFIG_VALUE == MPU6050_GYRO_FS_250
    #define GYRO_SCALE_FACTOR 131.0F
#elif GYRO_CONFIG_VALUE == MPU6050_GYRO_FS_500
    #define GYRO_SCALE_FACTOR 65.5F
#elif GYRO_CONFIG_VALUE == MPU6050_GYRO_FS_1000
    #define GYRO_SCALE_FACTOR 32.8F
#elif GYRO_CONFIG_VALUE == MPU6050_GYRO_FS_2000
    #define GYRO_SCALE_FACTOR 16.4F
#endif

#if ACC_CONFIG_VALUE == MPU6050_ACCEL_FS_2
    #define ACC_SCALE_FACTOR 16384.0F
#elif ACC_CONFIG_VALUE == MPU6050_ACCEL_FS_4
    #define ACC_SCALE_FACTOR 8192.0F
#elif ACC_CONFIG_VALUE == MPU6050_ACCEL_FS_8
    #define ACC_SCALE_FACTOR 4096.0F
#elif ACC_CONFIG_VALUE == MPU6050_ACCEL_FS_16
    #define ACC_SCALE_FACTOR 2048.0F
#endif

#endif // CURRENT_CONFIG_H

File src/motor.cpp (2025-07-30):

#include "motor.h"

volatile int32_t M1_encoderCount = 0;
volatile int32_t M2_encoderCount = 0;
volatile int32_t M3_encoderCount = 0;

volatile float M1_command[2] = {0.0f};
volatile float M2_command[2] = {0.0f};
volatile float M3_command[2] = {0.0f};

volatile float M1_error[2] = {0.0f};
volatile float M2_error[2] = {0.0f};
volatile float M3_error[2] = {0.0f};

volatile float M1_targetRPM = 0.0f;
volatile float M2_targetRPM = 0.0f;
volatile float M3_targetRPM = 0.0f;

void M1_PID(float targetRPM, float currentRPM){
    M1_error[1] = M1_error[0];
    M1_error[0] = fabsf(targetRPM) - fabsf(currentRPM);

    M1_command[1] = M1_command[0];
    M1_command[0] = M1_PID_COEF[0] * M1_command[1] + M1_PID_COEF[1] * M1_error[0] + M1_PID_COEF[2] * M1_error[1];

    if(M1_command[0] > 255.0f) M1_command[0] = 255.0f;
    else if(M1_command[0] < -255.0f) M1_command[0] = -255.0f;
    int8_t direction = (targetRPM >= 0) ? 1 : -1; 

    controlMotor(M1_ID, (float) direction * M1_command[0]);
}

void M2_PID(float targetRPM, float currentRPM){
    M2_error[1] = M2_error[0];
    M2_error[0] = fabsf(targetRPM) - fabsf(currentRPM);

    M2_command[1] = M2_command[0];
    M2_command[0] = M2_PID_COEF[0] * M2_command[1] + M2_PID_COEF[1] * M2_error[0] + M2_PID_COEF[2] * M2_error[1];

    if(M2_command[0] > 255.0f) M2_command[0] = 255.0f;
    else if(M2_command[0] < -255.0f) M2_command[0] = -255.0f;
    int8_t direction = (targetRPM >= 0) ? 1 : -1; 

    controlMotor(M2_ID, (float) direction * M2_command[0]);
}

void M3_PID(float targetRPM, float currentRPM){
    M3_error[1] = M3_error[0];
    M3_error[0] = fabsf(targetRPM) - fabsf(currentRPM);

    M3_command[1] = M3_command[0];
    M3_command[0] = M3_PID_COEF[0] * M3_command[1] + M3_PID_COEF[1] * M3_error[0] + M3_PID_COEF[2] * M3_error[1];

    if(M3_command[0] > 255.0f) M3_command[0] = 255.0f;
    else if(M3_command[0] < -255.0f) M3_command[0] = -255.0f;
    int8_t direction = (targetRPM >= 0) ? 1 : -1; 

    controlMotor(M3_ID, (float) direction * M3_command[0]);
}

void controlMotor(uint8_t motorID, float pulseValue){
    uint8_t motorPin;
    uint8_t directionPin;

    switch(motorID){
        case M1_ID: {
            motorPin = M1_PWM;
            directionPin = M1_DIR;
            break;
        }
        case M2_ID: {
            motorPin = M2_PWM;
            directionPin = M2_DIR;
            break;
        }
        case M3_ID: {
            motorPin = M3_PWM;
            directionPin = M3_DIR;
            break;
        }
        default:
            return;
    }

    if(pulseValue > 0) digitalWrite(directionPin, LOW);
    else digitalWrite(directionPin, HIGH);

    #ifdef DEBUG_MOTORS_ENABLED
        Serial.printf("----- Motor ID %d -----\n", motorID);
        Serial.printf("PWM pin: %d\nDirection pin: %d\nPWM pulse: %.4f\n", motorPin, directionPin, pulseValue);
    #endif

    ledcWrite(motorPin, fabsf(pulseValue));
}

void M1_updateEncoder(){
    int32_t signalA = digitalRead(M1_ENC_SIG_A);
    int32_t signalB = digitalRead(M1_ENC_SIG_B);

    if(signalA == signalB) M1_encoderCount++;
    else M1_encoderCount--;
}

void M2_updateEncoder(){
    int32_t signalA = digitalRead(M2_ENC_SIG_A);
    int32_t signalB = digitalRead(M2_ENC_SIG_B);

    if(signalA == signalB) M2_encoderCount++;
    else M2_encoderCount--;
}

void M3_updateEncoder(){
    int32_t signalA = digitalRead(M3_ENC_SIG_A);
    int32_t signalB = digitalRead(M3_ENC_SIG_B);

    if(signalA == signalB) M3_encoderCount++;
    else M3_encoderCount--;
}

void brakeMotor(uint8_t motorID, bool brake){
    uint8_t brakePin = 0;
    
    switch(motorID){
        case M1_ID: {
            brakePin = M1_EN;
            break;
        }
        case M2_ID: {
            brakePin = M2_EN;
            break;
        }
        case M3_ID: {
            brakePin = M3_EN;
            break;
        }
        default:
            return;
    }
    #ifdef DEBUG_MOTORS_ENABLED
        Serial.printf("> Motor ID %d brake: %d\n", motorID, brake);
    #endif

    if(brake) digitalWrite(brakePin, HIGH);
    else digitalWrite(brakePin, LOW);
}

void setTargetRPM(uint8_t motorID, float targetRPM){
    switch(motorID){
        case M1_ID: {
            M1_targetRPM = targetRPM;
            break;
        }
        case M2_ID: {
            M2_targetRPM = targetRPM;
            break;
        }
        case M3_ID: {
            M3_targetRPM = targetRPM;
            break;
        }
        default:
            return;
    }

    #ifdef DEBUG_MOTORS_ENABLED
        Serial.printf("> Motor ID %d set target RPM: %d\n", motorID, targetRPM);
    #endif
}

void processCommand(String command){
    int8_t spaceIndex = command.indexOf(' ');

    if(spaceIndex == -1) return;

    String firstPart = command.substring(0, spaceIndex);
    String secondPart = command.substring(spaceIndex + 1);

    int32_t motorID = firstPart.toInt();
    String valueStr = secondPart;

    // Check if the second part is a number
    bool isNumber = true;
    for (size_t i = 0; i < valueStr.length(); i++) {
        char c = valueStr.charAt(i);
        if (!isDigit(c) && !(i == 0 && c == '-')) {
            isNumber = false;
            break;
        }
    }

    #ifdef DEBUG_MOTORS_ENABLED
        Serial.printf("Received command for motor ID %d: %s\n", motorID, valueStr);
    #endif

    if(isNumber) setTargetRPM(motorID, valueStr.toFloat());
    else if(valueStr == "stop"){
        setTargetRPM(motorID, 0.0f);
        controlMotor(motorID, 0.0f);
        brakeMotor(motorID, true);
    }
    else if(valueStr == "start"){
        brakeMotor(motorID, false);
    }  
}

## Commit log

2025-07-23 Create complementary filter (doesn't work yet)
    [main.cpp, utils.cpp]
2025-07-23 Activate debug mode in I2C library
2025-07-24 Implement complementary filter
2025-07-24 Add motor control Add current documentation
    [Battery holder.stl, Corner piece v25.stl, Motor mounting bracket v13.stl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]
2025-07-30 Implement PID
2025-07-30 Update 3D model
    [Battery bracket.stl, Battery holder.stl, Support.stl]
